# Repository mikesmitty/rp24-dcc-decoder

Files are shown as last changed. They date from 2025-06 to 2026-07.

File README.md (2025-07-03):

# rp24-dcc-decoder
DIY DCC decoder for model railroad locomotives in an E24 form factor suitable for N scale/gauge locomotives

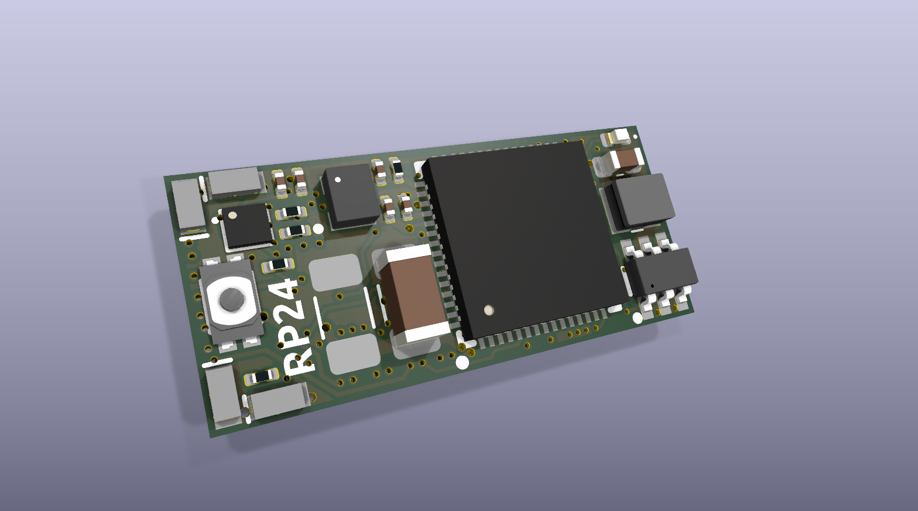
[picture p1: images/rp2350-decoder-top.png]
decoder top

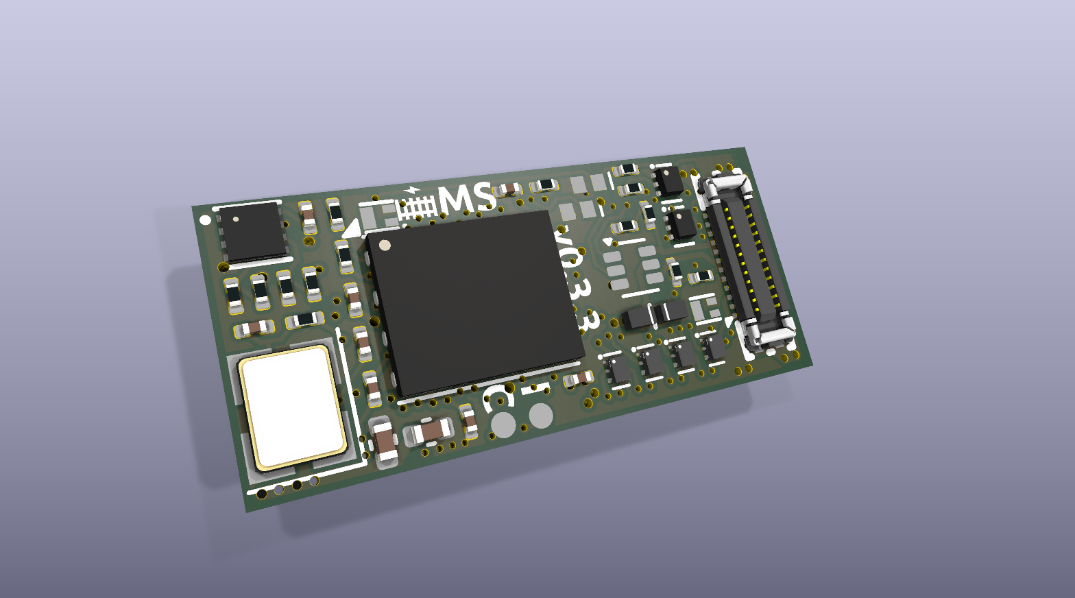
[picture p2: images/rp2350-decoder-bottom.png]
decoder bottom


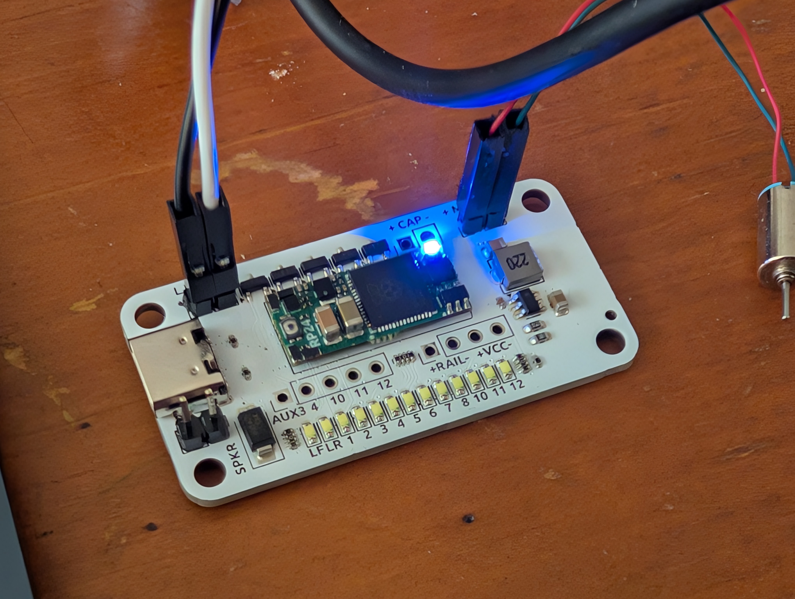
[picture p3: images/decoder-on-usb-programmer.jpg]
decoder on USB programmer

[Decoder identifying to JMRI](https://www.youtube.com/watch?v=m5kexSfDo3k)

## Features
- 8x MOSFET-switched functions
- 5x GPIO pins (3.3V input/output)
- Up to 0.75A motor current
- E24 form factor (approx 20mm x 9mm)
- i2s audio speaker output
- 12V nominal rail voltage (16V max)

# USB Programmer/E24 Tester
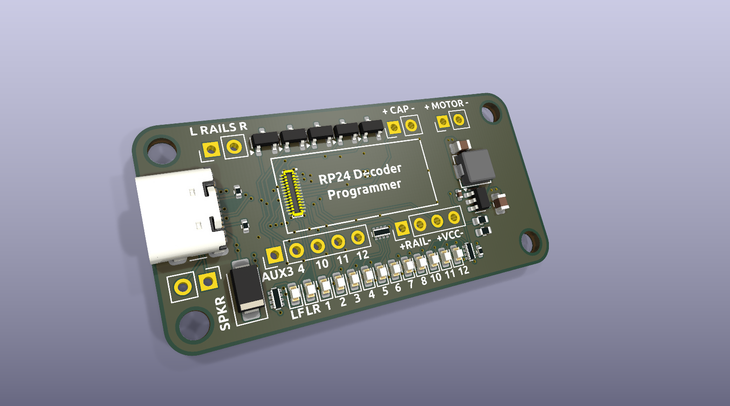
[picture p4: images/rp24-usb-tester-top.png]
programmer top

- USB-C port for easy programming and loading sound files
- Onboard LEDs for all aux outputs for simple decoder testing
- Breakout header for most E24 pins, including speaker, motor, rectified rail power, Vcc, plus all five E24 GPIO pins (Aux 3, 4, 10, 11, 12)
- Programming track input header allows for stationary decoder testing and CV programming

# RP24 Decoder Pinout
| E24 Pin | Function | GPIO Pin |
| --- | --- | --- |
| 1 | Speaker- | USB D- |
| 2 | Speaker+ | USB D+ |
| 3 | GND | GND |
| 4-5 | Motor- | N/A |
| 6-7 | Motor+ | N/A |
| 8 | Cap+ | GPIO20 |
| 9 | Lamp Front | GPIO6 (MOSFET) |
| 10 | Lamp Rear | GPIO7 (MOSFET) |
| 11 | AUX1 | GPIO8 (MOSFET) |
| 12 | AUX2 | GPIO5 (MOSFET) |
| 13 | AUX8 | GPIO4 (MOSFET) |
| 14 | AUX7 | GPIO3 (MOSFET) |
| 15 | AUX6 | GPIO9 (MOSFET) |
| 16 | AUX5 | GPIO2 (MOSFET) |
| 17 | U+ | DC Rail Voltage |
| 18 | Vcc | 3.3V |
| 19 | AUX10 | GPIO10 |
| 20 | AUX4 | GPIO13 |
| 21 | AUX3 | GPIO14 |
| 22 | GND | GND |
| 23 | AUX11 | GPIO0 |
| 24 | AUX12 | GPIO1 |
| N/A | Motor Driver A | GPIO25 |
| N/A | Motor Driver B | GPIO26 |
| N/A | Back EMF A | GPIO28 |
| N/A | Back EMF B | GPIO29 |
| N/A | DCC signal Left Rail | GPIO21 |
| N/A | DCC signal Right Rail | GPIO27 |
| N/A | RailCom Out | GPIO11 |
| N/A | Status LED | GPIO19 |
| N/A | i2s DIN | GPIO22 |
| N/A | i2s BCLK | GPIO23 |
| N/A | i2s LRCLK | GPIO24 |
| N/A | Charge external keepalive capacitor (PWM at very low duty cycle only) | GPIO20 |

# E24 Receiver/Wire Breakout Board
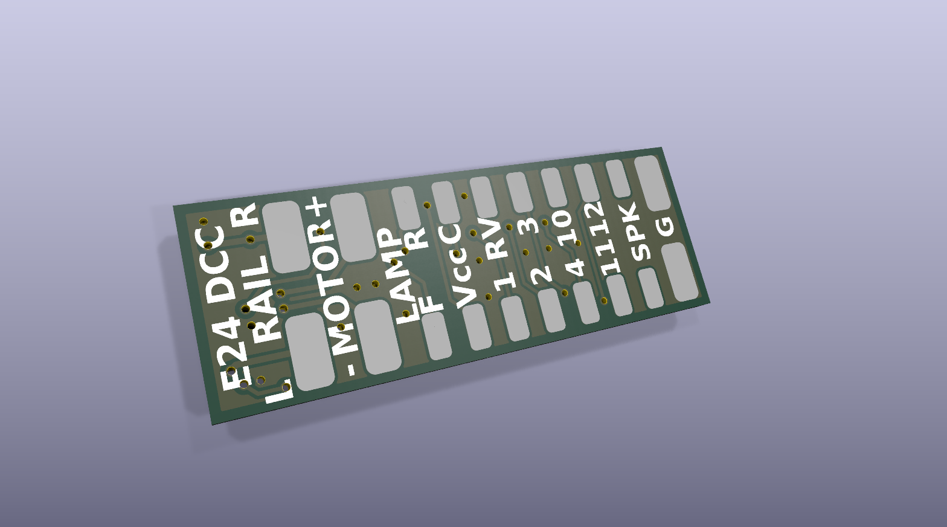
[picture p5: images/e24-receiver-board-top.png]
receiver top

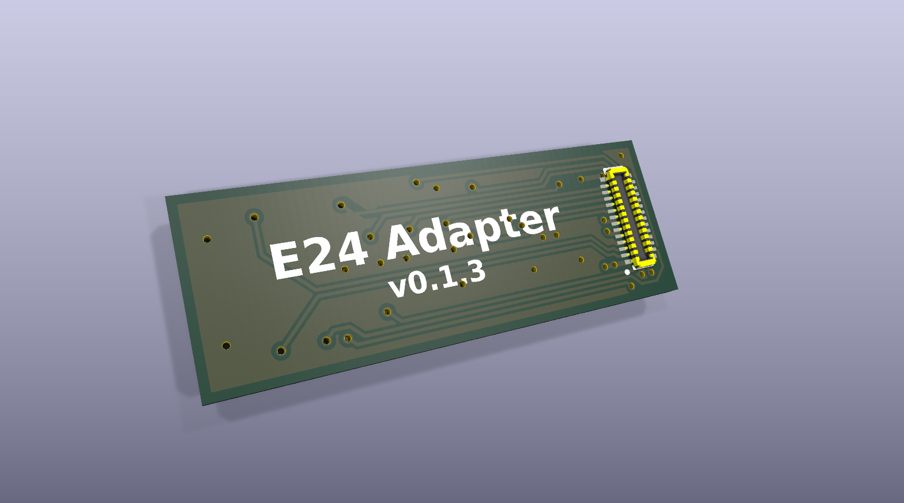
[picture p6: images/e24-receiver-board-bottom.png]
receiver bottom


## Receiver Board Solder Pads
| E24 Pin | Function | Label |
| --- | --- | --- |
| 1 | Speaker- | SPK |
| 2 | Speaker+ | SPK |
| 3 | GND | G |
| 4-5 | Motor- | - MOTOR + |
| 6-7 | Motor+ | - MOTOR + |
| 8 | External Capacitor+ | C |
| 9 | Lamp Front | F LAMP R |
| 10 | Lamp Rear | F LAMP R |
| 11 | AUX1 | 1 |
| 12 | AUX2 | 2 |
| 17 | DC Rail Voltage | RV |
| 18 | Microcontroller Voltage Output | Vcc |
| 19 | AUX10 | 10 |
| 20 | AUX4 | 4 |
| 21 | AUX3 | 3 |
| 22 | GND | G |
| 23 | AUX11 | 11 |
| 24 | AUX12 | 12 |

Inspired by the rp2040-decoder project by gab-k: https://github.com/gab-k/RP2040-Decoder

## Reference:
### E24
- RCD-124 (German): https://normen.railcommunity.de/RCD-124.pdf
- https://dccwiki.com/Locomotive_Interface/E24
### RailCom
- [NMRA S-9.3.2, Section 2](https://www.nmra.org/sites/default/files/s-9.3.2_2012_12_10.pdf)
- Example RailCom transmitter circuit: [CircuitJS](https://www.falstad.com/circuit/circuitjs.html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)

View this project on [CADLAB.io](https://cadlab.io/project/28797).

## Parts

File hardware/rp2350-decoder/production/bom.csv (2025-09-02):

Comment | Designator | Footprint | LCSC
LMBR4020H3T5G | D1,D2,D3,D4 | rp2350-decoder:U-DFN1608-2_L1.6-W0.8-RD | C2852608
MAX98357AEWL+T | U5 | rp2350-decoder:WLP-9_L1.4-W1.3-P0.40-R3-C3-BR | C2682619
100nF | C1,C4,C7,C12,C13,C14,C19 | rp2350-decoder:C_0201_0603Metric | C49062
1K | R2,R4,R5,R15,R17,R19 | rp2350-decoder:R_0201_0603Metric | C270365
6.8K | R1,R6,R7,R8,R12,R13,R16,R18 | rp2350-decoder:R_0201_0603Metric | C423451
AP63203WU | U2 | rp2350-decoder:TSOT-26_L2.9-W1.6-P0.95-LS2.8-BL | C780769
AP1606 | Q1,Q2 | rp2350-decoder:Diodes_DFN1006-3 | C2849580
BZX884C3V3 | D7,D8 | rp2350-decoder:DFN1006-2L-RD | C7529009
NST847BPDP6T5G | Q3,Q4 | rp2350-decoder:SOT-963 | C896443
BOOT | SW1 | rp2350-decoder:SW-SMD_4P-L2.6-W1.6-P0.75-LS3.0 | C913778
22R | R9,R10,R11 | rp2350-decoder:R_0201_0603Metric | C270355
2.2K | R3 | rp2350-decoder:R_0201_0603Metric | C473534
DMN2991UDA-7B | Q5,Q6,Q7,Q8 | rp2350-decoder:X2-DFN0806-6_L0.8-W0.6_X2-DFN0806-6 | C2937136
3.3uH | L2 | rp2350-decoder:L_pol_2016 | C42411119
4.7uF | C9,C10,C15,C17,C18 | rp2350-decoder:C_0201_0603Metric | C335103
RB161QS-40 | D5,D6 | rp2350-decoder:DIO-SMD_L1.0-W0.6-P0.65-RD | C5563750
MD9927 | U6 | rp2350-decoder:WDFN-8_L2.0-W2.0-P0.50-BL-EP | C2684662
47uF | C16 | rp2350-decoder:C_1206_3216Metric | C22367835
10pF | C8,C11 | rp2350-decoder:C_0201_0603Metric | C384956
5052702412 | J3 | rp2350-decoder:CONN-SMD_5052702412 | C724151
W25Q128JVPIQ | U3 | rp2350-decoder:WSON-8-1EP_6x5mm_P1.27mm_EP3.4x4.3mm | C190862
4.7uH | L1 | rp2350-decoder:IND-SMD_L2.5-W2.0-VLS252012CX-150M | C5832360
ABM8-272-T3 | Y1 | rp2350-decoder:Crystal_SMD_3225-4Pin_3.2x2.5mm | C20625731
NCS2220AMUT1G | U1 | rp2350-decoder:DFN-8_L1.6-W1.6-P0.40-BL-EP | C464059
2.2uF | C2,C3 | rp2350-decoder:C_0402_1005Metric | C159814
100uF | C6 | rp2350-decoder:C_1206_3216Metric | C15008
33R | R14 | rp2350-decoder:R_0201_0603Metric | C423356
Blue LED | D9 | rp2350-decoder:LED_0402_1005Metric | C130724
RP2350A | U4 | rp2350-decoder:QFN-60_L7.0-W7.0-P0.40-TL-EP3.4 | C42411118
22uF | C5 | rp2350-decoder:C_0603_1608Metric | C86295

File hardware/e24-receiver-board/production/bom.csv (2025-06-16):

Comment | Designator | Footprint | LCSC
505070-2422 | J1 | e24-receiver-board:CONN-SMD_24P-P0.35_5050702422 | C724143

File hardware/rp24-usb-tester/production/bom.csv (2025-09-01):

Comment | Designator | Footprint | LCSC
22uF | C1,C3 | rp24-usb-tester:C_0805_2012Metric | C45783
SS34 | D13 | rp24-usb-tester:D_SMA | C8678
15K | R4 | rp24-usb-tester:R_0603_1608Metric | C22809
WHITE_LED | D1,D2,D3,D4,D5,D6,D7,D8,D9,D10,D11,D12,D14 | rp24-usb-tester:LED_0603_1608Metric | C2290
505070-2422 | J4 | rp24-usb-tester:CONN-SMD_24P-P0.35_5050702422 | C724143
5.1K | R1,R2 | rp24-usb-tester:R_0402_1005Metric | C25905
USB_C_Receptacle_USB2.0_16P | P1 | rp24-usb-tester:USB_C_Receptacle_GCT_USB4105-xx-A_16P_TopMnt_Horizontal | C2765186
SS8050 | Q1,Q2,Q3,Q4,Q5 | rp24-usb-tester:SOT-23 | C2150
220R | RN1,RN2,RN3 | rp24-usb-tester:R_Array_Concave_4x0402 | C326868
100R | R5 | rp24-usb-tester:R_0402_1005Metric | C25076
22nF | C2 | rp24-usb-tester:C_0402_1005Metric | C1532
MT2492 | U1 | rp24-usb-tester:SOT-23-6 | C89358
22uH | L1 | rp24-usb-tester:IND-SMD_L4.6-W4.2_SMMS0420 | C2894720
110K | R3 | rp24-usb-tester:R_0603_1608Metric | C25805

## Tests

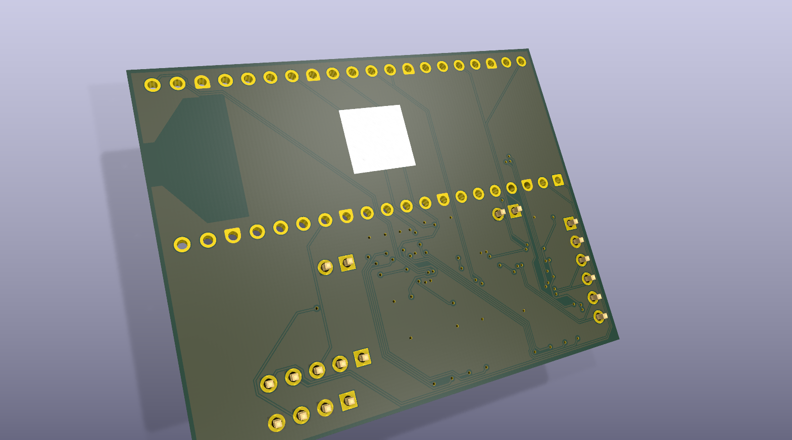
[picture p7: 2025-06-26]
images/pico2-test-mule-bottom.png

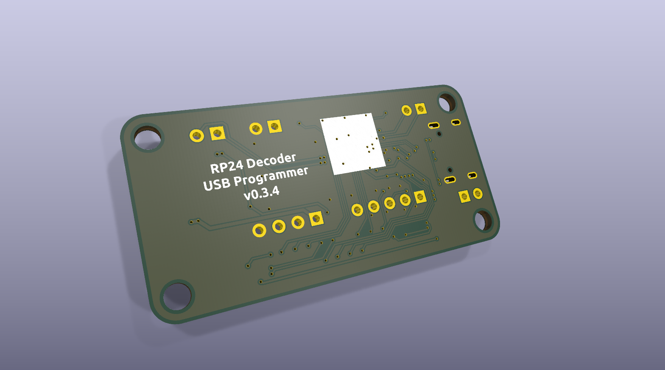
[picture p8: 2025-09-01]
images/rp24-usb-tester-bottom.png

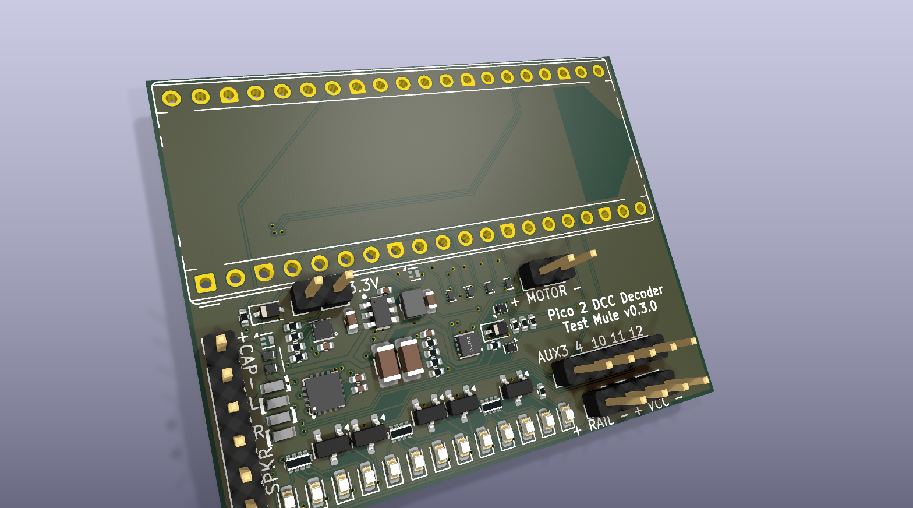
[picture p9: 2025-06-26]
images/pico2-test-mule-top.png

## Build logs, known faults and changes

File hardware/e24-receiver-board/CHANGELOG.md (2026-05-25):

# Changelog

## [0.1.3](https://github.com/mikesmitty/rp24-dcc-decoder/compare/e24-receiver-board-v0.1.2...e24-receiver-board-v0.1.3) (2026-05-25)

### Bug Fixes

* **e24-receiver-board:** switch to 1.0mm thick pcb ([0ce120b](https://github.com/mikesmitty/rp24-dcc-decoder/commit/0ce120b274af8b35ff21393b15e6bb2e795d1627))

## [0.1.2](https://github.com/mikesmitty/rp24-dcc-decoder/compare/e24-receiver-board-v0.1.1...e24-receiver-board-v0.1.2) (2025-06-18)

### Bug Fixes

* un-swap aux11/aux12 pins ([a4e7ca3](https://github.com/mikesmitty/rp24-dcc-decoder/commit/a4e7ca3ea81a5f14c1e2768d6be0322b92dff5f2))

## [0.1.1](https://github.com/mikesmitty/rp24-dcc-decoder/compare/e24-receiver-board-v0.1.0...e24-receiver-board-v0.1.1) (2025-02-23)

### Bug Fixes

* update to kicad 9.0 ([1caf43e](https://github.com/mikesmitty/rp24-dcc-decoder/commit/1caf43eae2056ed70c1e3e898e5bf193f2a6ef8b))

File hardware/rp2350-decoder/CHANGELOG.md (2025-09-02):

# Changelog

## [0.3.3](https://github.com/mikesmitty/rp24-dcc-decoder/compare/rp2350-decoder-v0.3.2...rp2350-decoder-v0.3.3) (2025-09-02)

### Bug Fixes

* clean up silkscreen items ([80477e9](https://github.com/mikesmitty/rp24-dcc-decoder/commit/80477e9bc5986381e135d9b4ac6735943684b929))

## [0.3.2](https://github.com/mikesmitty/rp24-dcc-decoder/compare/rp2350-decoder-v0.3.1...rp2350-decoder-v0.3.2) (2025-09-02)

### Bug Fixes

* switch rail ttl zeners to more common dfn1006 ([5c28789](https://github.com/mikesmitty/rp24-dcc-decoder/commit/5c2878904d47dc9064c75f49efb4027531c81caa))

## [0.3.1](https://github.com/mikesmitty/rp24-dcc-decoder/compare/rp2350-decoder-v0.3.0...rp2350-decoder-v0.3.1) (2025-08-02)

### Bug Fixes

* remove vdc from under connector ([96dd000](https://github.com/mikesmitty/rp24-dcc-decoder/commit/96dd00003e3252300e009753ae7b70a3d9992b5f))

## [0.3.0](https://github.com/mikesmitty/rp24-dcc-decoder/compare/rp2350-decoder-v0.2.0...rp2350-decoder-v0.3.0) (2025-07-03)

### Features

* detect right rail instead of VDC ([ddb6ea3](https://github.com/mikesmitty/rp24-dcc-decoder/commit/ddb6ea383b4f5dc82e747a8a50b871392123b382))

## [0.2.0](https://github.com/mikesmitty/rp24-dcc-decoder/compare/rp2350-decoder-v0.1.2...rp2350-decoder-v0.2.0) (2025-06-26)

### Features

* zener diodes to detect both waves and cutouts ([e85a1f7](https://github.com/mikesmitty/rp24-dcc-decoder/commit/e85a1f764ec8e276c3f0ad8270ab0958ef19c064))

### Bug Fixes

* un-swap capacitor shutdown circuit inputs ([61e69d1](https://github.com/mikesmitty/rp24-dcc-decoder/commit/61e69d1b25d5a35320f998b9ed846dfaee792550))

## [0.1.2](https://github.com/mikesmitty/rp24-dcc-decoder/compare/rp2350-decoder-v0.1.1...rp2350-decoder-v0.1.2) (2025-06-18)

### Bug Fixes

* un-swap usb +/- and aux11/aux12 pins ([1f776d0](https://github.com/mikesmitty/rp24-dcc-decoder/commit/1f776d04f63d8f8768ab01cb2be59e1d0c34c532))

## [0.1.1](https://github.com/mikesmitty/rp24-dcc-decoder/compare/rp2350-decoder-v0.1.0...rp2350-decoder-v0.1.1) (2025-04-01)

### Bug Fixes

* use shorter cap on bottom ([dc6b62a](https://github.com/mikesmitty/rp24-dcc-decoder/commit/dc6b62acc13467da5e2ec5f99067f5d8a516d0b7))

## [0.1.0](https://github.com/mikesmitty/rp24-dcc-decoder/compare/rp2350-decoder-v0.0.4...rp2350-decoder-v0.1.0) (2025-03-14)

### Bug Fixes

* add ground vias near motor driver ([d3c346b](https://github.com/mikesmitty/rp24-dcc-decoder/commit/d3c346b67aaa05e254f0cf5fc2168e786e9e2e42))

### Miscellaneous Chores

* refresh gerbers ([5a95ecd](https://github.com/mikesmitty/rp24-dcc-decoder/commit/5a95ecdd13cb824ea14429b33e8ac43790169a54))

## [0.0.4](https://github.com/mikesmitty/rp24-dcc-decoder/compare/rp2350-decoder-v0.0.3...rp2350-decoder-v0.0.4) (2025-03-08)

### Bug Fixes

* update DCC_TTL debounce capacitor value ([732472c](https://github.com/mikesmitty/rp24-dcc-decoder/commit/732472c98f50376903bb764d93151fdd62facd41))

## [0.0.3](https://github.com/mikesmitty/rp24-dcc-decoder/compare/rp2350-decoder-v0.0.2...rp2350-decoder-v0.0.3) (2025-02-27)

### Bug Fixes

* add debounce capacitor to dcc signal gate ([e6d63b1](https://github.com/mikesmitty/rp24-dcc-decoder/commit/e6d63b166735f56c2b0e96776631d385dbaa79c0))
* update debounce cap value ([7167d29](https://github.com/mikesmitty/rp24-dcc-decoder/commit/7167d2950df77b2c3e97060f00c1a36faaa49821))

## [0.0.2](https://github.com/mikesmitty/rp24-dcc-decoder/compare/rp2350-decoder-v0.0.1...rp2350-decoder-v0.0.2) (2025-02-21)

### Bug Fixes

* lower gate voltage to the dcc signal mosfet ([6cb97c4](https://github.com/mikesmitty/rp24-dcc-decoder/commit/6cb97c431d6f1eea73aafedfe1a02bb732defedf))

## 0.0.1 (2025-02-19)

### Bug Fixes

* switch to recommended crystal ([3851f21](https://github.com/mikesmitty/rp24-dcc-decoder/commit/3851f218dc31737b537c2cfd6a0378fb10ac53e3))

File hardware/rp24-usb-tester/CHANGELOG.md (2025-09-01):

# Changelog

## [0.3.4](https://github.com/mikesmitty/rp24-dcc-decoder/compare/rp24-usb-tester-v0.3.3...rp24-usb-tester-v0.3.4) (2025-09-01)

### Bug Fixes

* 5.1k resistors go to gnd ([8d3d4cb](https://github.com/mikesmitty/rp24-dcc-decoder/commit/8d3d4cb1ccdc5ea720a21019bf442bf9b9f3356d))

## [0.3.3](https://github.com/mikesmitty/rp24-dcc-decoder/compare/rp24-usb-tester-v0.3.2...rp24-usb-tester-v0.3.3) (2025-06-26)

### Bug Fixes

* bump resistors to make LEDs less blinding ([2c4b003](https://github.com/mikesmitty/rp24-dcc-decoder/commit/2c4b00311665386e5128b5ffa2d54e06a1cdbff7))

## [0.3.2](https://github.com/mikesmitty/rp24-dcc-decoder/compare/rp24-usb-tester-v0.3.1...rp24-usb-tester-v0.3.2) (2025-06-18)

### Bug Fixes

* un-swap usb +/- and aux11/aux12 pins ([1f776d0](https://github.com/mikesmitty/rp24-dcc-decoder/commit/1f776d04f63d8f8768ab01cb2be59e1d0c34c532))

## [0.3.1](https://github.com/mikesmitty/rp24-dcc-decoder/compare/rp24-usb-tester-v0.3.0...rp24-usb-tester-v0.3.1) (2025-02-23)

### Bug Fixes

* update fonts and update to kicad 9.0 ([708d73b](https://github.com/mikesmitty/rp24-dcc-decoder/commit/708d73b6243eea81ae5f8e1142ea019fc21d64b7))

## [0.3.0](https://github.com/mikesmitty/rp24-dcc-decoder/compare/rp24-usb-tester-v0.2.0...rp24-usb-tester-v0.3.0) (2025-02-16)

### Features

* add new e24 decoder tester/rp24 programmer ([2115cfc](https://github.com/mikesmitty/rp24-dcc-decoder/commit/2115cfca512d0ccf7c0052a0154a3ae7812805ee))

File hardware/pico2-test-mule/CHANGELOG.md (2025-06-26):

# Changelog

## [0.3.0](https://github.com/mikesmitty/rp24-dcc-decoder/compare/pico2-test-mule-v0.2.5...pico2-test-mule-v0.3.0) (2025-06-26)

### Features

* zener diodes to detect both waves and cutouts ([4520e62](https://github.com/mikesmitty/rp24-dcc-decoder/commit/4520e620aadee4b4d5b46caad65a14fe12c72eaa))

## [0.2.5](https://github.com/mikesmitty/rp24-dcc-decoder/compare/pico2-test-mule-v0.2.4...pico2-test-mule-v0.2.5) (2025-06-26)

### Bug Fixes

* un-swap capacitor shutdown circuit inputs ([61e69d1](https://github.com/mikesmitty/rp24-dcc-decoder/commit/61e69d1b25d5a35320f998b9ed846dfaee792550))

## [0.2.4](https://github.com/mikesmitty/rp24-dcc-decoder/compare/pico2-test-mule-v0.2.3...pico2-test-mule-v0.2.4) (2025-03-08)

### Bug Fixes

* reduce DCC_TTL gate voltage ([8bb2ff3](https://github.com/mikesmitty/rp24-dcc-decoder/commit/8bb2ff398a00977e3ff73f020af28f2f82988a62))
* tweak DCC_TTL debounce cap value ([8bb2ff3](https://github.com/mikesmitty/rp24-dcc-decoder/commit/8bb2ff398a00977e3ff73f020af28f2f82988a62))

## [0.2.3](https://github.com/mikesmitty/rp24-dcc-decoder/compare/pico2-test-mule-v0.2.2...pico2-test-mule-v0.2.3) (2025-02-27)

### Bug Fixes

* combine left side headers ([8ec852f](https://github.com/mikesmitty/rp24-dcc-decoder/commit/8ec852fca5bbab5de6a5f5c44ad002712fa8c7b9))
* minor trace rerouting ([e47bcee](https://github.com/mikesmitty/rp24-dcc-decoder/commit/e47bceee5babf562b35d44f7a8becf1b144da8fe))

## [0.2.2](https://github.com/mikesmitty/rp24-dcc-decoder/compare/pico2-test-mule-v0.2.1...pico2-test-mule-v0.2.2) (2025-02-26)

### Bug Fixes

* add debounce capacitor to dcc signal gate ([8eee1f6](https://github.com/mikesmitty/rp24-dcc-decoder/commit/8eee1f6eb663765a5d2aa30e55fa527f804a481f))

## [0.2.1](https://github.com/mikesmitty/rp24-dcc-decoder/compare/pico2-test-mule-v0.2.0...pico2-test-mule-v0.2.1) (2025-02-23)

### Bug Fixes

* update to kicad 9.0 ([98311b6](https://github.com/mikesmitty/rp24-dcc-decoder/commit/98311b61241b5b43cae7abeaa5af38be45a82724))

## [0.2.0](https://github.com/mikesmitty/rp24-dcc-decoder/compare/pico2-test-mule-v0.1.0...pico2-test-mule-v0.2.0) (2025-02-16)

### Features

* add new pico2 test mule for firmware dev ([0d0d831](https://github.com/mikesmitty/rp24-dcc-decoder/commit/0d0d831cf1059fa60065890cc0ef8ffa47a683c0))

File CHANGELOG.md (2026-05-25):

# Changelog

## [0.6.0](https://github.com/mikesmitty/rp24-dcc-decoder/compare/v0.5.1...v0.6.0) (2026-05-25)

### Features

* Update module github.com/tinygo-org/pio to v0.3.0 ([#76](https://github.com/mikesmitty/rp24-dcc-decoder/issues/76)) ([c56449e](https://github.com/mikesmitty/rp24-dcc-decoder/commit/c56449e195b2d09360eefeda9650cc8935bdbf73))

### Bug Fixes

* **deps:** update golang.org/x/exp digest to 74f9aab ([#72](https://github.com/mikesmitty/rp24-dcc-decoder/issues/72)) ([b6f4512](https://github.com/mikesmitty/rp24-dcc-decoder/commit/b6f4512f8ab333e81455b3949f5a69fc011e2c3c))
* **deps:** update golang.org/x/exp digest to e25ba8c ([#68](https://github.com/mikesmitty/rp24-dcc-decoder/issues/68)) ([ddd0e29](https://github.com/mikesmitty/rp24-dcc-decoder/commit/ddd0e299a88e69853f8f733d55ec5d8c079d945e))
* Update module github.com/mikesmitty/tinypid to v1.1.2 ([#66](https://github.com/mikesmitty/rp24-dcc-decoder/issues/66)) ([368d651](https://github.com/mikesmitty/rp24-dcc-decoder/commit/368d651679ab84afcd6bbbe5192ec00418eea2de))

## [0.5.1](https://github.com/mikesmitty/rp24-dcc-decoder/compare/v0.5.0...v0.5.1) (2025-10-31)

### Bug Fixes

* **deps:** update golang.org/x/exp digest to 42675ad ([#55](https://github.com/mikesmitty/rp24-dcc-decoder/issues/55)) ([8c79fb0](https://github.com/mikesmitty/rp24-dcc-decoder/commit/8c79fb0a1e2817a186f70df58597ea7953df09a9))
* **deps:** update golang.org/x/exp digest to 51f8813 ([#51](https://github.com/mikesmitty/rp24-dcc-decoder/issues/51)) ([7244902](https://github.com/mikesmitty/rp24-dcc-decoder/commit/724490245d16994d8783d3452a990d92a2ad6594))
* **deps:** update golang.org/x/exp digest to 8b4c13b ([#56](https://github.com/mikesmitty/rp24-dcc-decoder/issues/56)) ([41abde0](https://github.com/mikesmitty/rp24-dcc-decoder/commit/41abde0aa6662b7aac0c94eba1e1472ebc4626d6))
* **deps:** update golang.org/x/exp digest to a4bb9ff ([#64](https://github.com/mikesmitty/rp24-dcc-decoder/issues/64)) ([0dec770](https://github.com/mikesmitty/rp24-dcc-decoder/commit/0dec7704e9ae3c3ff21456ee4219fc70a096a228))
* **deps:** update golang.org/x/exp digest to d2f985d ([#63](https://github.com/mikesmitty/rp24-dcc-decoder/issues/63)) ([2d0001a](https://github.com/mikesmitty/rp24-dcc-decoder/commit/2d0001a6984248e023278804a349cace2932afc7))
* **deps:** update golang.org/x/exp digest to df92998 ([#61](https://github.com/mikesmitty/rp24-dcc-decoder/issues/61)) ([d0d50a4](https://github.com/mikesmitty/rp24-dcc-decoder/commit/d0d50a4dca40c667b3305ba84ea4512c51026bc5))

## [0.5.0](https://github.com/mikesmitty/rp24-dcc-decoder/compare/v0.4.0...v0.5.0) (2025-08-02)

### Features

* add early stage backemf motor control ([a25211d](https://github.com/mikesmitty/rp24-dcc-decoder/commit/a25211db5da32ed0f17aac7e8010aa097b95d403))
* add watchdog for signal cutout ([a25211d](https://github.com/mikesmitty/rp24-dcc-decoder/commit/a25211db5da32ed0f17aac7e8010aa097b95d403))

### Bug Fixes

* add watchdog timer ([11b6576](https://github.com/mikesmitty/rp24-dcc-decoder/commit/11b657602e25fd6cb13ee2e36697979c7ffdf19e))
* defend against panics from invalid messages ([ffdcd00](https://github.com/mikesmitty/rp24-dcc-decoder/commit/ffdcd002d98769922d42dc0cb6c4ae6520a1eed1))
* **deps:** update golang.org/x/exp digest to 645b1fa ([#48](https://github.com/mikesmitty/rp24-dcc-decoder/issues/48)) ([313a73c](https://github.com/mikesmitty/rp24-dcc-decoder/commit/313a73c76a07aca35d5ec08aace8f12d40190b84))

## [0.4.0](https://github.com/mikesmitty/rp24-dcc-decoder/compare/v0.3.0...v0.4.0) (2025-07-03)

### Features

* detect right rail instead of VDC ([ddb6ea3](https://github.com/mikesmitty/rp24-dcc-decoder/commit/ddb6ea383b4f5dc82e747a8a50b871392123b382))

### Bug Fixes

* fix cv write bugs ([bde219d](https://github.com/mikesmitty/rp24-dcc-decoder/commit/bde219d6429ba6914b5c6cf0a966d8f1f6285c03))

## [0.3.0](https://github.com/mikesmitty/rp24-dcc-decoder/compare/v0.2.0...v0.3.0) (2025-07-02)

### Features

* add basic ack functionality ([f5d5ae6](https://github.com/mikesmitty/rp24-dcc-decoder/commit/f5d5ae6a7456e60b06a05bcb1aa5879a4456d067))
* overhaul motor controller ([99d4ee8](https://github.com/mikesmitty/rp24-dcc-decoder/commit/99d4ee804c4e48eec4de7833bd355d6945b4c168))

### Bug Fixes

* add missing import ([c64d183](https://github.com/mikesmitty/rp24-dcc-decoder/commit/c64d183ea62e0248e458cf550c6ac9474b331468))
* enable motor control lockout mutex ([a0d5d45](https://github.com/mikesmitty/rp24-dcc-decoder/commit/a0d5d454318a02a385601f88090ae5ff6baa3785))

## [0.2.0](https://github.com/mikesmitty/rp24-dcc-decoder/compare/v0.1.0...v0.2.0) (2025-03-23)

### Features

* add motor control ([26f15c5](https://github.com/mikesmitty/rp24-dcc-decoder/commit/26f15c5dfaf2c012a957807f6a8c6f23504239b2))
* update go to 1.24.1 ([fa4d50e](https://github.com/mikesmitty/rp24-dcc-decoder/commit/fa4d50ecfa9deb2a11a8e6c42269f53fc977b5fc))

### Bug Fixes

* correct function offset indexes ([ea1fa88](https://github.com/mikesmitty/rp24-dcc-decoder/commit/ea1fa88235f76972585350e53caf278e261eab66))
* disable directional outputs when switching direction ([26f15c5](https://github.com/mikesmitty/rp24-dcc-decoder/commit/26f15c5dfaf2c012a957807f6a8c6f23504239b2))
* embed tagged version at build time ([009c713](https://github.com/mikesmitty/rp24-dcc-decoder/commit/009c713c4f9f1269592b5a993daec2d3cb00894c))

## [0.1.0](https://github.com/mikesmitty/rp24-dcc-decoder/compare/v0.0.1...v0.1.0) (2025-03-23)

### Features

* add function/output mapping and general cleanup ([d0cb788](https://github.com/mikesmitty/rp24-dcc-decoder/commit/d0cb788c2bafbf0a5f7e7699384653fa242ed265))
* add initial rough draft packages ([94049e1](https://github.com/mikesmitty/rp24-dcc-decoder/commit/94049e1630e36b6ee2894b043c71bf0edd1b20ed))

### Bug Fixes

* clean up motor CV definitions ([ddde344](https://github.com/mikesmitty/rp24-dcc-decoder/commit/ddde344ea2ec8ca0b557756d1d70a4cd0f5d16f2))
* cleanup and recategorize future changes ([19ba12f](https://github.com/mikesmitty/rp24-dcc-decoder/commit/19ba12f27c25d43e626b6c9f27d5b2940e60cd3c))
* **deps:** update module github.com/tinygo-org/pio to v0.2.0 ([#29](https://github.com/mikesmitty/rp24-dcc-decoder/issues/29)) ([1cd45db](https://github.com/mikesmitty/rp24-dcc-decoder/commit/1cd45db01dc1dcfaa50f6969206e61af102fbd75))
* handle double uno-reverse direction of travel swaps ([be3c416](https://github.com/mikesmitty/rp24-dcc-decoder/commit/be3c4161fb6095494123a71e18ab77e418a75bd7))
* implement CV21/CV22 consist function masks ([5bd3659](https://github.com/mikesmitty/rp24-dcc-decoder/commit/5bd3659a5e1a80b0e5bbf3bf347243e021f56986))
* load new index when CV31/CV32 are set ([5bd3659](https://github.com/mikesmitty/rp24-dcc-decoder/commit/5bd3659a5e1a80b0e5bbf3bf347243e021f56986))
* make dcc functions map to outputs ([8c448f2](https://github.com/mikesmitty/rp24-dcc-decoder/commit/8c448f22cd591466faf243c840eda684ffdd44ae))
* misc cleanup and add CVs ([d987945](https://github.com/mikesmitty/rp24-dcc-decoder/commit/d98794585a2216fc0b2ad298861d51faa18c7f80))
* squash various bugs ([8c448f2](https://github.com/mikesmitty/rp24-dcc-decoder/commit/8c448f22cd591466faf243c840eda684ffdd44ae))
* undo copy/paste bugs ([cc430f6](https://github.com/mikesmitty/rp24-dcc-decoder/commit/cc430f6f70852d3c441f914362f6252d59be9529))

## 0.0.1 (2025-02-16)

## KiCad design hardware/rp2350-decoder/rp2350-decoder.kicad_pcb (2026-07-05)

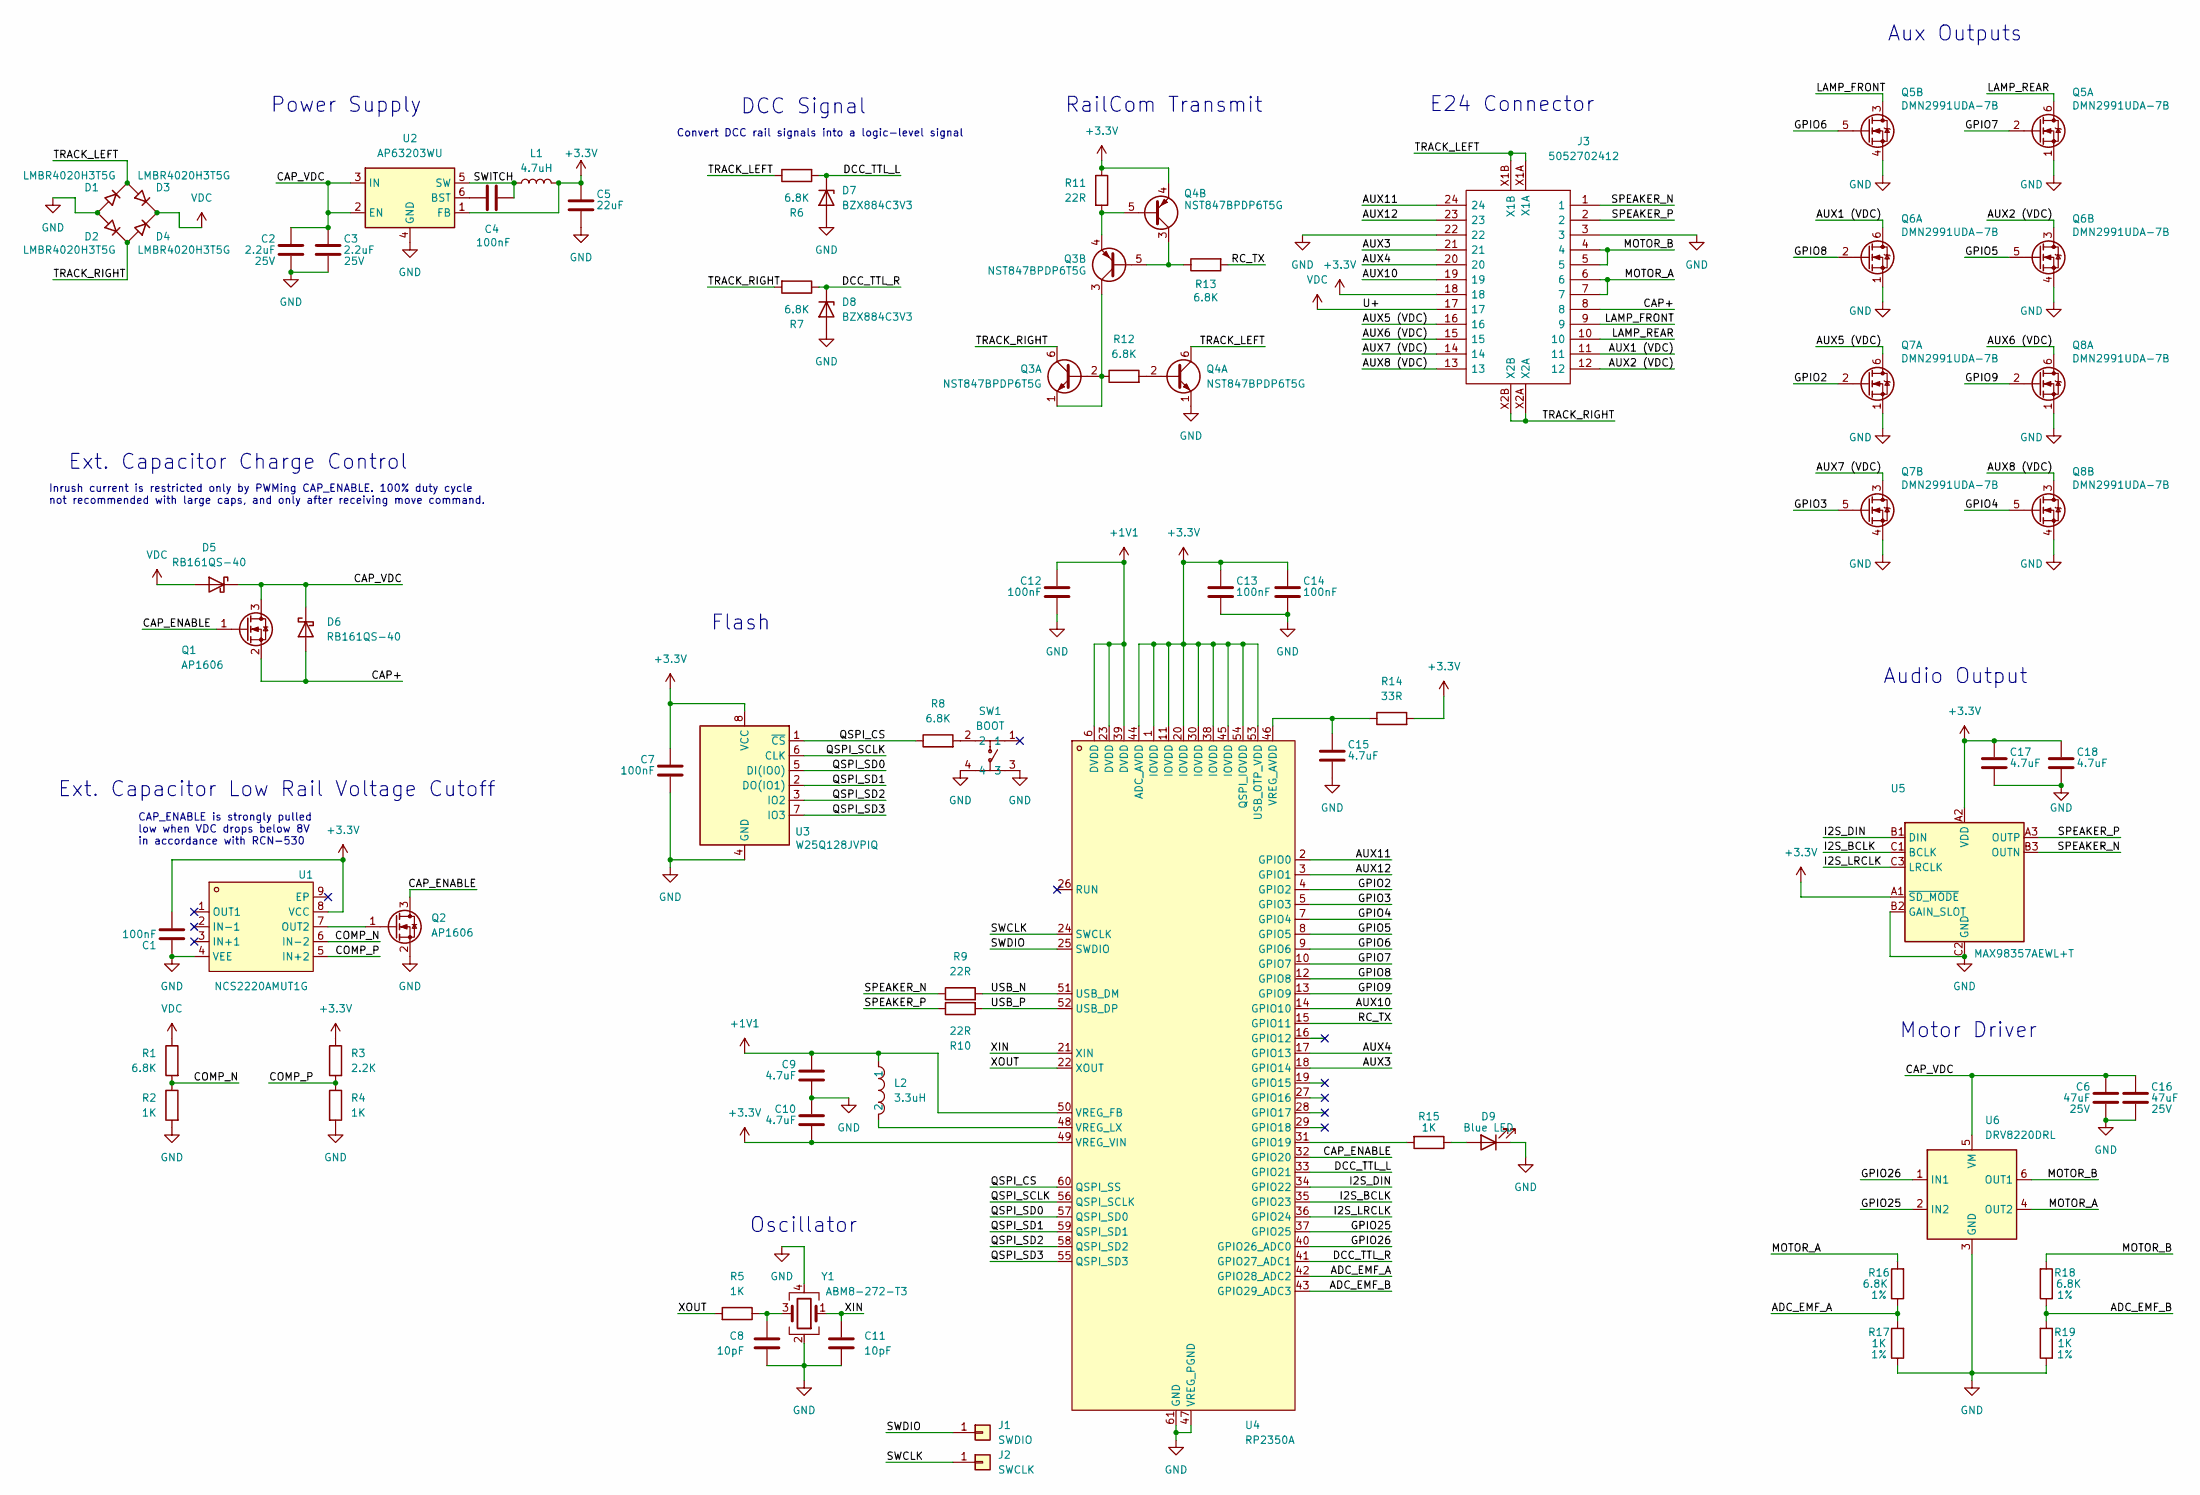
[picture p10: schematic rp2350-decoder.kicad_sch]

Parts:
C1, C4, C7, C12, C13, C14: 100nF; C_0201_0603Metric; LCSC C49062
C2, C3: 2.2uF; C_0402_1005Metric; Voltage 25V; LCSC C159814
C5: 22uF; C_0603_1608Metric; LCSC C86295
C6, C16: 47uF; C_1206_3216Metric; Voltage 25V; LCSC C22367835
C8, C11: 10pF; C_0201_0603Metric; LCSC C384956
C9, C10, C15, C17, C18: 4.7uF; C_0201_0603Metric; LCSC C335103
D1, D2, D3, D4: LMBR4020H3T5G; U-DFN1608-2_L1.6-W0.8-RD; LCSC C2852608
D5, D6: RB161QS-40; DIO-SMD_L1.0-W0.6-P0.65-RD; LCSC C5563750
D7, D8: BZX884C3V3; DFN1006-2L-RD; LCSC C7529009
D9: Blue LED; LED_0402_1005Metric; LCSC C130724
J1: SWDIO; Pogo Pad 0.8mm
J2: SWCLK; Pogo Pad 0.8mm
J3: 5052702412; CONN-SMD_5052702412; LCSC C724151
L1: 4.7uH; IND-SMD_L2.5-W2.0-VLS252012CX-150M; LCSC C5832360
L2: 3.3uH; L_pol_2016; LCSC C42411119
Q1, Q2: AP1606; Diodes_DFN1006-3; LCSC C2849580
Q3, Q4: NST847BPDP6T5G; SOT-963; LCSC C896443
Q5, Q6, Q7, Q8: DMN2991UDA-7B; X2-DFN0806-6_L0.8-W0.6_X2-DFN0806-6; LCSC C2937136
R1, R6, R7, R8, R12, R13: 6.8K; R_0201_0603Metric; LCSC C423451
R2, R4, R5, R15: 1K; R_0201_0603Metric; LCSC C270365
R3: 2.2K; R_0201_0603Metric; LCSC C473534
R9, R10, R11: 22R; R_0201_0603Metric; LCSC C270355
R14: 33R; R_0201_0603Metric; LCSC C423356
R16, R18: 6.8K; R_0201_0603Metric; Tolerance 1%; LCSC C423451
R17, R19: 1K; R_0201_0603Metric; Tolerance 1%; LCSC C270365
SW1: BOOT; SW-SMD_4P-L2.6-W1.6-P0.75-LS3.0; LCSC C913778
U1: NCS2220AMUT1G; DFN-8_L1.6-W1.6-P0.40-BL-EP; LCSC C464059
U2: AP63203WU; TSOT-26_L2.9-W1.6-P0.95-LS2.8-BL; LCSC C780769
U3: W25Q128JVPIQ; WSON-8-1EP_6x5mm_P1.27mm_EP3.4x4.3mm; LCSC C190862
U4: RP2350A; QFN-60_L7.0-W7.0-P0.40-TL-EP3.4; LCSC C42411118
U5: MAX98357AEWL+T; WLP-9_L1.4-W1.3-P0.40-R3-C3-BR; LCSC C2682619
U6: DRV8220DRL; SOT-563; LCSC C3681351
Y1: ABM8-272-T3; Crystal_SMD_3225-4Pin_3.2x2.5mm; LCSC C20625731

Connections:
+1V1: C9.1, C12.1, L2.1, U4.6 (DVDD), U4.23 (DVDD), U4.39 (DVDD), U4.50 (VREG_FB)
+3.3V: C1.2, C5.1, C7.1, C10.2, C13.1, C14.1, C17.1, C18.1, J3.18, L1.2, Q4.4 (E2), R3.1, R11.1, R14.2, U1.8 (VCC), U2.1 (FB), U3.8 (VCC), U4.1 (IOVDD), U4.11 (IOVDD), U4.20 (IOVDD), U4.30 (IOVDD), U4.38 (IOVDD), U4.44 (ADC_AVDD), U4.45 (IOVDD), U4.49 (VREG_VIN), U4.53 (USB_OTP_VDD), U4.54 (QSPI_IOVDD), U5.A1 (~SD_MODE), U5.A2 (VDD)
/ADC_EMF_A: R16.1, R17.2, U4.42 (GPIO28_ADC2)
/ADC_EMF_B: R18.1, R19.2, U4.43 (GPIO29_ADC3)
/AUX1 (VDC): J3.11, Q6.6 (D1)
/AUX2 (VDC): J3.12, Q6.3 (D2)
/AUX3: J3.21, U4.18 (GPIO14)
/AUX4: J3.20, U4.17 (GPIO13)
/AUX5 (VDC): J3.16, Q7.6 (D1)
/AUX6 (VDC): J3.15, Q8.6 (D1)
/AUX7 (VDC): J3.14, Q7.3 (D2)
/AUX8 (VDC): J3.13, Q8.3 (D2)
/AUX10: J3.19, U4.14 (GPIO10)
/AUX11: J3.24, U4.2 (GPIO0)
/AUX12: J3.23, U4.3 (GPIO1)
/CAP+: D6.2 (A), J3.8, Q1.2 (S)
/CAP_ENABLE: Q1.1 (G), Q2.3 (D), U4.32 (GPIO20)
/CAP_VDC: C2.1, C3.1, C6.1, C16.1, D5.1 (K), D6.1 (K), Q1.3 (D), U2.2 (EN), U2.3 (IN), U6.5 (VM)
/COMP_N: R1.2, R2.1, U1.6 (IN−2)
/COMP_P: R3.2, R4.1, U1.5 (IN+2)
/DCC_TTL_L: D7.1 (K), R6.2, U4.33 (GPIO21)
/DCC_TTL_R: D8.1 (K), R7.1, U4.41 (GPIO27_ADC1)
/GPIO2: Q7.2 (G1), U4.4 (GPIO2)
/GPIO3: Q7.5 (G2), U4.5 (GPIO3)
/GPIO4: Q8.5 (G2), U4.7 (GPIO4)
/GPIO5: Q6.5 (G2), U4.8 (GPIO5)
/GPIO6: Q5.5 (G2), U4.9 (GPIO6)
/GPIO7: Q5.2 (G1), U4.10 (GPIO7)
/GPIO8: Q6.2 (G1), U4.12 (GPIO8)
/GPIO9: Q8.2 (G1), U4.13 (GPIO9)
/GPIO25: U4.37 (GPIO25), U6.2 (IN2)
/GPIO26: U4.40 (GPIO26_ADC0), U6.1 (IN1)
/I2S_BCLK: U4.35 (GPIO23), U5.C1 (BCLK)
/I2S_DIN: U4.34 (GPIO22), U5.B1 (DIN)
/I2S_LRCLK: U4.36 (GPIO24), U5.C3 (LRCLK)
/LAMP_FRONT: J3.9, Q5.3 (D2)
/LAMP_REAR: J3.10, Q5.6 (D1)
/MOTOR_A: J3.6, J3.7, R16.2, U6.4 (OUT2)
/MOTOR_B: J3.4, J3.5, R18.2, U6.6 (OUT1)
/QSPI_CS: R8.1, U3.1 (~CS), U4.60 (QSPI_SS)
/QSPI_SCLK: U3.6 (CLK), U4.56 (QSPI_SCLK)
/QSPI_SD0: U3.5 (DI(IO0)), U4.57 (QSPI_SD0)
/QSPI_SD1: U3.2 (DO(IO1)), U4.59 (QSPI_SD1)
/QSPI_SD2: U3.3 (IO2), U4.58 (QSPI_SD2)
/QSPI_SD3: U3.7 (IO3), U4.55 (QSPI_SD3)
/RC_TX: R13.2, U4.15 (GPIO11)
/SPEAKER_N: J3.1, R9.1, U5.B3 (OUTN)
/SPEAKER_P: J3.2, R10.1, U5.A3 (OUTP)
/SWCLK: J2.1, U4.24 (SWCLK)
/SWDIO: J1.1, U4.25 (SWDIO)
/SWITCH: C4.2, L1.1, U2.5 (SW)
/TRACK_LEFT: D1.1 (K), D3.2 (A), J3.X1A, J3.X1B, Q4.6 (C1), R6.1
/TRACK_RIGHT: D2.1 (K), D4.2 (A), J3.X2A, J3.X2B, Q3.6 (C1), R7.2
/USB_N: R9.2, U4.51 (USB_DM)
/USB_P: R10.2, U4.52 (USB_DP)
/XIN: C11.1, U4.21 (XIN), Y1.1
/XOUT: R5.2, U4.22 (XOUT)
GND: C1.1, C2.2, C3.2, C5.2, C6.2, C7.2, C8.2, C9.2, C10.1, C11.2, C12.2, C13.2, C14.2, C15.2, C16.2, C17.2, C18.2, D1.2 (A), D2.2 (A), D7.2 (A), D8.2 (A), D9.1 (K), J3.3, J3.22, Q2.2 (S), Q4.1 (E1), Q5.1 (S1), Q5.4 (S2), Q6.1 (S1), Q6.4 (S2), Q7.1 (S1), Q7.4 (S2), Q8.1 (S1), Q8.4 (S2), R2.2, R4.2, R17.1, R19.1, SW1.3, SW1.4, U1.4 (VEE), U2.4 (GND), U3.4 (GND), U3.9 (GND), U4.47 (VREG_PGND), U4.61 (GND), U5.B2 (GAIN_SLOT), U5.C2 (GND), U6.3 (GND), Y1.2, Y1.4
unnamed: C8.1, R5.1, Y1.3
unnamed: D9.2 (A), R15.1
unnamed: Q2.1 (G), U1.7 (OUT2)
unnamed: Q3.1 (E1), Q3.2 (B1), Q3.3 (C2), R12.1
unnamed: Q3.5 (B2), Q4.3 (C2), R13.1
unnamed: Q3.4 (E2), Q4.5 (B2), R11.2
unnamed: Q4.2 (B1), R12.2
unnamed: R8.2, SW1.2
unnamed: C4.1, U2.6 (BST)
unnamed: R15.2, U4.31 (GPIO19)
unnamed: C15.1, R14.1, U4.46 (VREG_AVDD)
unnamed: L2.2, U4.48 (VREG_LX)
VDC: D3.1 (K), D4.1 (K), D5.2 (A), J3.17, R1.1

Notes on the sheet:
Inrush current is restricted only by PWMing CAP_ENABLE. 100% duty cycle not recommended with large caps, and only after receiving move command.
CAP_ENABLE is strongly pulled low when VDC drops below 8V in accordance with RCN-530
Aux Outputs
RailCom Transmit
Convert DCC rail signals into a logic-level signal
Motor Driver
Oscillator
Power Supply
Flash
Ext. Capacitor Low Rail Voltage Cutoff
Ext. Capacitor Charge Control
Audio Output
E24 Connector
DCC Signal

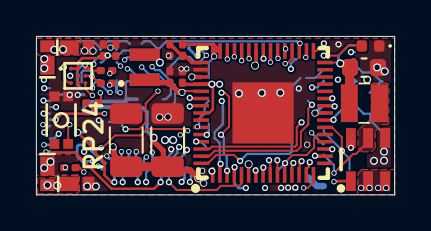
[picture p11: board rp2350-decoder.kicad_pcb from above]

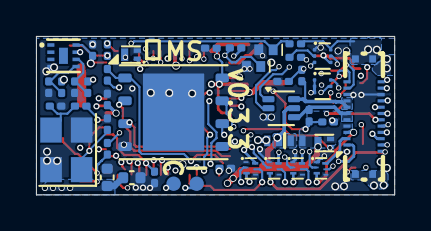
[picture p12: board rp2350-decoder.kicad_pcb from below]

Board: 6 copper layers, 19.9 x 8.8 mm, 67 parts (43 on the bottom side), 71 nets.

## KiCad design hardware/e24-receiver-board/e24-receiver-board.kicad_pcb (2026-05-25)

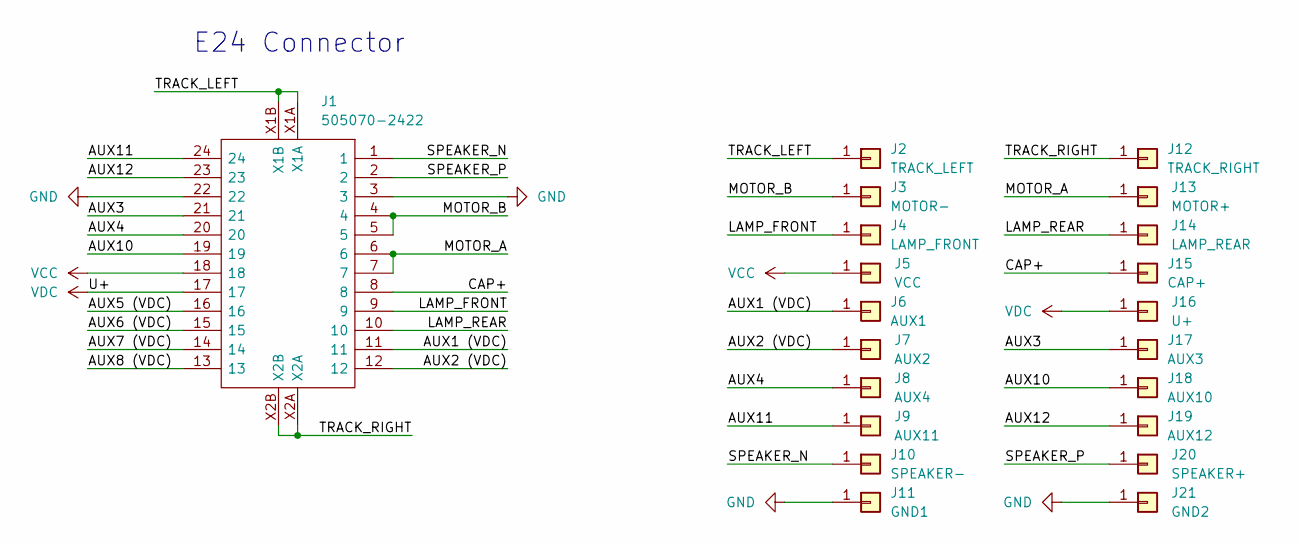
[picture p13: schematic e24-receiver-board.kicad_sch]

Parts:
J1: 505070-2422; CONN-SMD_24P-P0.35_5050702422; Manufacturer_Part_Number 505070-2422; LCSC C724143
J2: TRACK_LEFT; SolderWirePad_1x01_SMD_1.5x3mm
J3: MOTOR-; SolderWirePad_1x01_SMD_1.5x3mm
J4: LAMP_FRONT; SolderWirePad_1x01_SMD_1x2mm
J5: VCC; SolderWirePad_1x01_SMD_1x2mm
J6: AUX1; SolderWirePad_1x01_SMD_1x2mm
J7: AUX2; SolderWirePad_1x01_SMD_1x2mm
J8: AUX4; SolderWirePad_1x01_SMD_1x2mm
J9: AUX11; SolderWirePad_1x01_SMD_1x2mm
J10: SPEAKER-; SolderWirePad_1x01_SMD_1x2mm
J11: GND1; SolderWirePad_1x01_SMD_1.5x3mm
J12: TRACK_RIGHT; SolderWirePad_1x01_SMD_1.5x3mm
J13: MOTOR+; SolderWirePad_1x01_SMD_1.5x3mm
J14: LAMP_REAR; SolderWirePad_1x01_SMD_1x2mm
J15: CAP+; SolderWirePad_1x01_SMD_1x2mm
J16: U+; SolderWirePad_1x01_SMD_1x2mm
J17: AUX3; SolderWirePad_1x01_SMD_1x2mm
J18: AUX10; SolderWirePad_1x01_SMD_1x2mm
J19: AUX12; SolderWirePad_1x01_SMD_1x2mm
J20: SPEAKER+; SolderWirePad_1x01_SMD_1x2mm
J21: GND2; SolderWirePad_1x01_SMD_1.5x3mm

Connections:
/AUX1 (VDC): J1.11, J6.1
/AUX2 (VDC): J1.12, J7.1
/AUX3: J1.21, J17.1
/AUX4: J1.20, J8.1
/AUX5 (VDC): J1.16
/AUX6 (VDC): J1.15
/AUX7 (VDC): J1.14
/AUX8 (VDC): J1.13
/AUX10: J1.19, J18.1
/AUX11: J1.24, J9.1
/AUX12: J1.23, J19.1
/CAP+: J1.8, J15.1
/LAMP_FRONT: J1.9, J4.1
/LAMP_REAR: J1.10, J14.1
/MOTOR_A: J1.6, J1.7, J13.1
/MOTOR_B: J1.4, J1.5, J3.1
/SPEAKER_N: J1.1, J10.1
/SPEAKER_P: J1.2, J20.1
/TRACK_LEFT: J1.X1A, J1.X1B, J2.1
/TRACK_RIGHT: J1.X2A, J1.X2B, J12.1
GND: J1.3, J1.22, J11.1, J21.1
VCC: J1.18, J5.1
VDC: J1.17, J16.1

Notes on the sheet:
E24 Connector

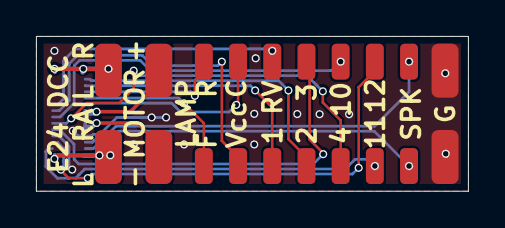
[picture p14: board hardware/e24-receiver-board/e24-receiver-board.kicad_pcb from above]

Board: 2 copper layers, 24.0 x 8.6 mm, 21 parts (1 on the bottom side), 19 nets.

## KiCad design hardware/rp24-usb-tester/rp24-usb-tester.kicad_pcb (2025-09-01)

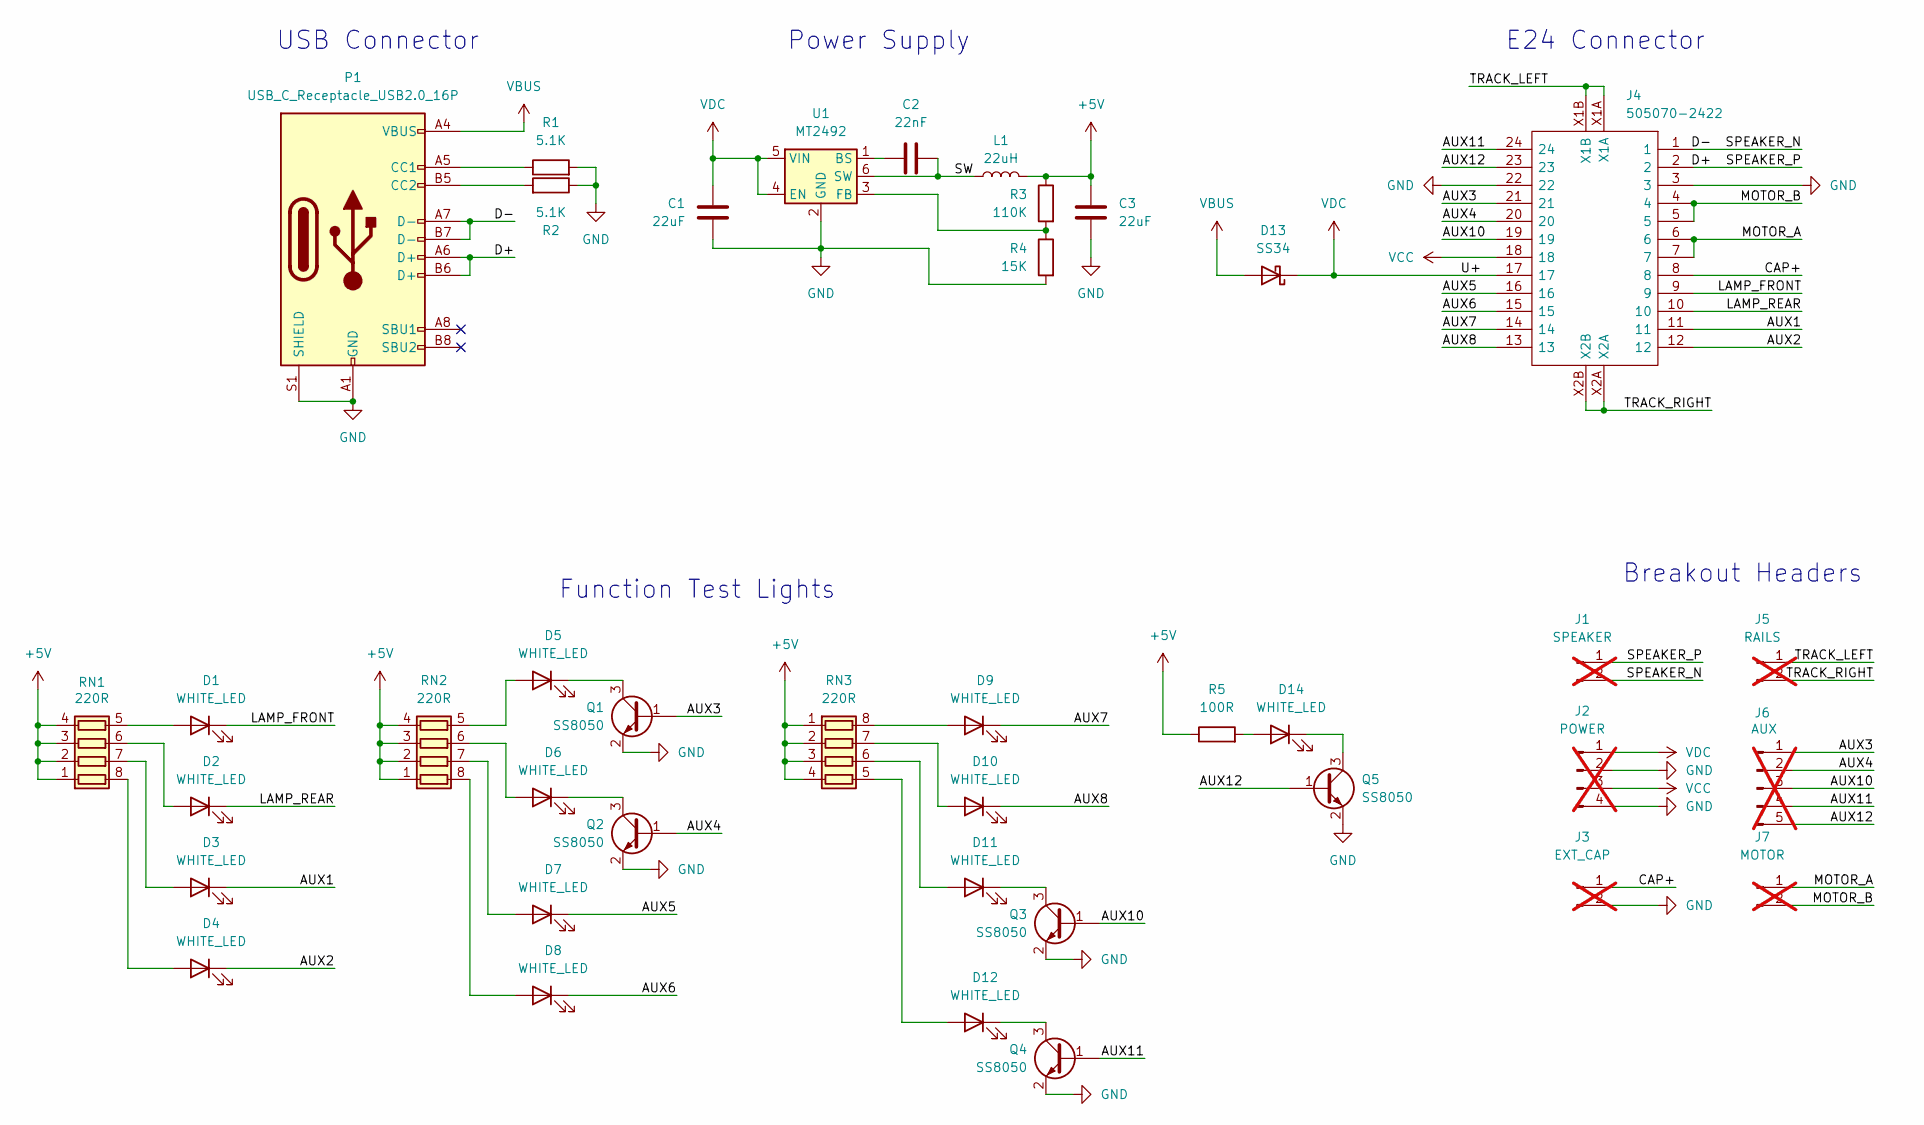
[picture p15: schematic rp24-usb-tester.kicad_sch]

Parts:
C1, C3: 22uF; C_0805_2012Metric; LCSC C45783
C2: 22nF; C_0402_1005Metric; LCSC C1532
D1, D2, D3, D4, D5, D6, D7, D8, D9, D10, D11, D12, D14: WHITE_LED; LED_0603_1608Metric; LCSC C2290
D13: SS34; D_SMA; LCSC C8678
J1: SPEAKER; PinHeader_1x02_P2.54mm_Vertical; not fitted
J2: POWER; PinHeader_1x04_P2.54mm_Vertical; not fitted
J3: EXT_CAP; PinHeader_1x02_P2.54mm_Vertical; not fitted
J4: 505070-2422; CONN-SMD_24P-P0.35_5050702422; Manufacturer_Part_Number 505070-2422; LCSC C724143
J5: RAILS; PinHeader_1x02_P2.54mm_Vertical; not fitted
J6: AUX; PinHeader_1x05_P2.54mm_Vertical; not fitted
J7: MOTOR; PinHeader_1x02_P2.54mm_Vertical; not fitted
L1: 22uH; IND-SMD_L4.6-W4.2_SMMS0420; LCSC C2894720
P1: USB_C_Receptacle_USB2.0_16P; USB_C_Receptacle_GCT_USB4105-xx-A_16P_TopMnt_Horizontal; LCSC C2765186
Q1, Q2, Q3, Q4, Q5: SS8050; SOT-23; LCSC C2150
R1, R2: 5.1K; R_0402_1005Metric; LCSC C25905
R3: 110K; R_0603_1608Metric; LCSC C25805
R4: 15K; R_0603_1608Metric; LCSC C22809
R5: 100R; R_0402_1005Metric; LCSC C25076
RN1, RN2, RN3: 220R; R_Array_Concave_4x0402; LCSC C326868
U1: MT2492; SOT-23-6; LCSC C89358

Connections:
+5V: C3.1, L1.2, R3.1, R5.1, RN1.1 (R1.1), RN1.2 (R2.1), RN1.3 (R3.1), RN1.4 (R4.1), RN2.1 (R1.1), RN2.2 (R2.1), RN2.3 (R3.1), RN2.4 (R4.1), RN3.1 (R1.1), RN3.2 (R2.1), RN3.3 (R3.1), RN3.4 (R4.1)
/AUX1: D3.1 (K), J4.11
/AUX2: D4.1 (K), J4.12
/AUX3: J4.21, J6.1, Q1.1 (B)
/AUX4: J4.20, J6.2, Q2.1 (B)
/AUX5: D7.1 (K), J4.16
/AUX6: D8.1 (K), J4.15
/AUX7: D9.1 (K), J4.14
/AUX8: D10.1 (K), J4.13
/AUX10: J4.19, J6.3, Q3.1 (B)
/AUX11: J4.24, J6.4, Q4.1 (B)
/AUX12: J4.23, J6.5, Q5.1 (B)
/CAP+: J3.1, J4.8
/D+: J1.1, J4.2, P1.A6 (D+), P1.B6 (D+)
/D-: J1.2, J4.1, P1.A7 (D-), P1.B7 (D-)
/LAMP_FRONT: D1.1 (K), J4.9
/LAMP_REAR: D2.1 (K), J4.10
/MOTOR_A: J4.6, J4.7, J7.1
/MOTOR_B: J4.4, J4.5, J7.2
/SW: C2.2, L1.1, U1.6 (SW)
/TRACK_LEFT: J4.X1A, J4.X1B, J5.1
/TRACK_RIGHT: J4.X2A, J4.X2B, J5.2
GND: C1.2, C3.2, J2.2, J2.4, J3.2, J4.3, J4.22, P1.A1 (GND), P1.A12 (GND), P1.B1 (GND), P1.B12 (GND), P1.S1 (SHIELD), Q1.2 (E), Q2.2 (E), Q3.2 (E), Q4.2 (E), Q5.2 (E), R1.2, R2.1, R4.2, U1.2 (GND)
unnamed: D1.2 (A), RN1.5 (R4.2)
unnamed: D2.2 (A), RN1.6 (R3.2)
unnamed: D3.2 (A), RN1.7 (R2.2)
unnamed: D4.2 (A), RN1.8 (R1.2)
unnamed: D5.2 (A), RN2.5 (R4.2)
unnamed: D5.1 (K), Q1.3 (C)
unnamed: D6.2 (A), RN2.6 (R3.2)
unnamed: D6.1 (K), Q2.3 (C)
unnamed: D7.2 (A), RN2.7 (R2.2)
unnamed: D8.2 (A), RN2.8 (R1.2)
unnamed: D9.2 (A), RN3.8 (R1.2)
unnamed: D10.2 (A), RN3.7 (R2.2)
unnamed: D11.2 (A), RN3.6 (R3.2)
unnamed: D11.1 (K), Q3.3 (C)
unnamed: D12.2 (A), RN3.5 (R4.2)
unnamed: D12.1 (K), Q4.3 (C)
unnamed: D14.2 (A), R5.2
unnamed: D14.1 (K), Q5.3 (C)
unnamed: P1.A5 (CC1), R1.1
unnamed: P1.B5 (CC2), R2.2
unnamed: C2.1, U1.1 (BS)
unnamed: R3.2, R4.1, U1.3 (FB)
VBUS: D13.2 (A), P1.A4 (VBUS), P1.A9 (VBUS), P1.B4 (VBUS), P1.B9 (VBUS)
VCC: J2.3, J4.18
VDC: C1.1, D13.1 (K), J2.1, J4.17, U1.4 (EN), U1.5 (VIN)

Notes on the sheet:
Function Test Lights
Breakout Headers
E24 Connector
Power Supply
USB Connector

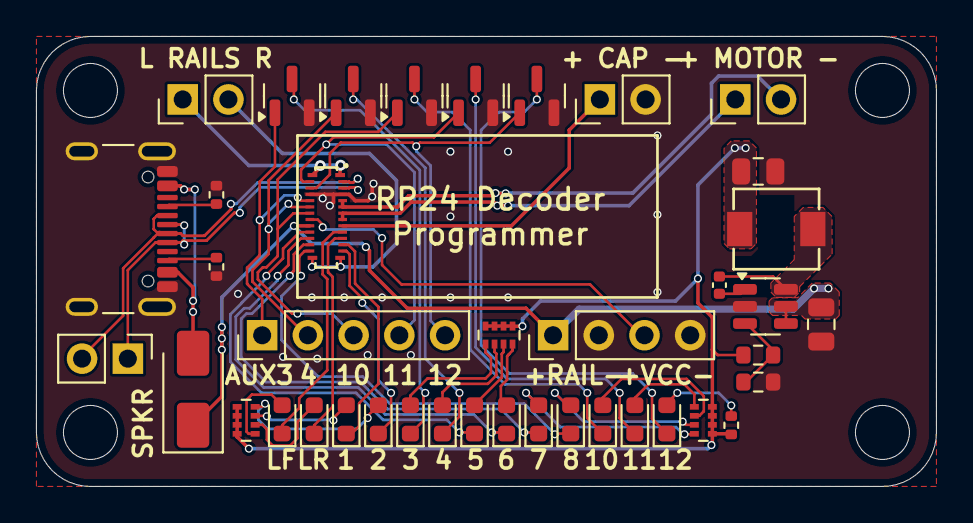
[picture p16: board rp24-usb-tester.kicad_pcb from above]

Board: 2 copper layers, 50.0 x 25.0 mm, 40 parts (0 on the bottom side), 48 nets.

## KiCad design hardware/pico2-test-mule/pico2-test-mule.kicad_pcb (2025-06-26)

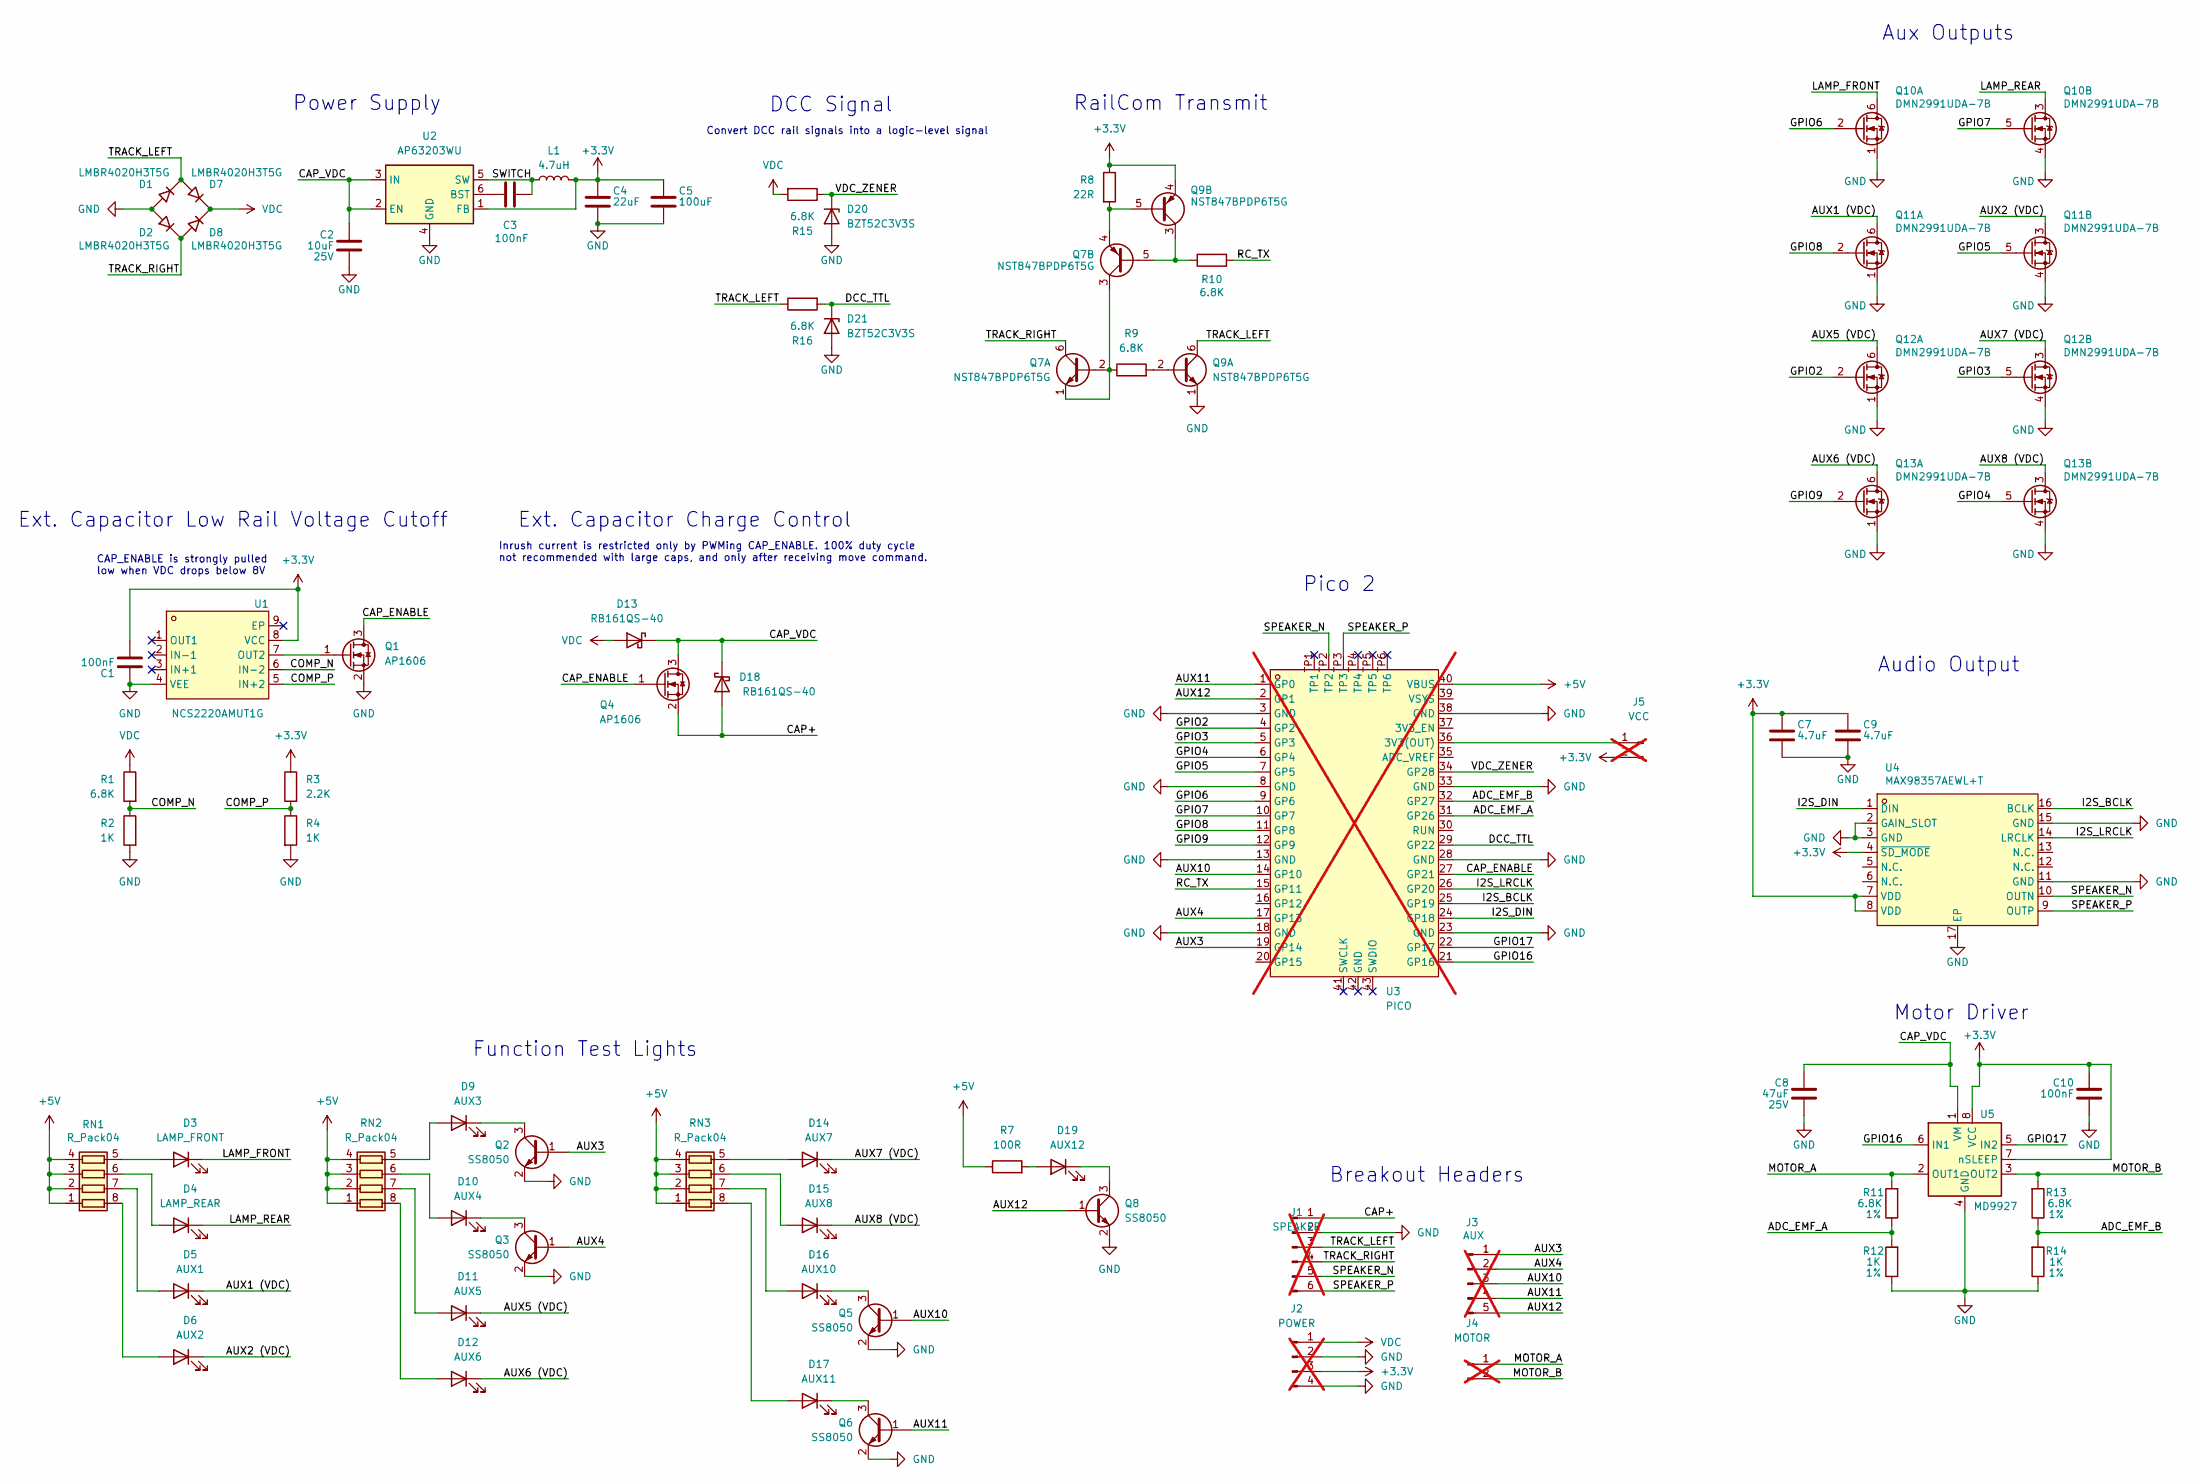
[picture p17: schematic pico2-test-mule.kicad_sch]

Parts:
C1, C3, C10: 100nF; C_0402_1005Metric; LCSC C1525
C2: 10uF; C_0603_1608Metric; Voltage 25V; LCSC C96446
C4: 22uF; C_0603_1608Metric; LCSC C86295
C5: 100uF; C_1206_3216Metric; LCSC C15008
C7, C9: 4.7uF; C_0402_1005Metric; LCSC C307423
C8: 47uF; C_1206_3216Metric; Voltage 25V; LCSC C22367835
D1, D2, D7, D8: LMBR4020H3T5G; U-DFN1608-2_L1.6-W0.8-RD; LCSC C2852608
D3: LAMP_FRONT; LED_0603_1608Metric; LCSC C2290
D4: LAMP_REAR; LED_0603_1608Metric; LCSC C2290
D5: AUX1; LED_0603_1608Metric; LCSC C2290
D6: AUX2; LED_0603_1608Metric; LCSC C2290
D9: AUX3; LED_0603_1608Metric; LCSC C2290
D10: AUX4; LED_0603_1608Metric; LCSC C2290
D11: AUX5; LED_0603_1608Metric; LCSC C2290
D12: AUX6; LED_0603_1608Metric; LCSC C2290
D13, D18: RB161QS-40; DIO-SMD_L1.0-W0.6-P0.65-RD; LCSC C5563750
D14: AUX7; LED_0603_1608Metric; LCSC C2290
D15: AUX8; LED_0603_1608Metric; LCSC C2290
D16: AUX10; LED_0603_1608Metric; LCSC C2290
D17: AUX11; LED_0603_1608Metric; LCSC C2290
D19: AUX12; LED_0603_1608Metric; LCSC C2290
D20, D21: BZT52C3V3S; D_SOD-323; LCSC C19077437
J1: SPEAKER; PinHeader_1x06_P2.54mm_Vertical; not fitted
J2: POWER; PinHeader_1x04_P2.54mm_Vertical; not fitted
J3: AUX; PinHeader_1x05_P2.54mm_Vertical; not fitted
J4: MOTOR; PinHeader_1x02_P2.54mm_Vertical; not fitted
J5: VCC; PinHeader_1x02_P2.54mm_Vertical; not fitted
L1: 4.7uH; IND-SMD_L2.5-W2.0-VLS252012CX-150M; LCSC C5832360
Q1, Q4: AP1606; Diodes_DFN1006-3; LCSC C2849580
Q2, Q3, Q5, Q6, Q8: SS8050; SOT-23; LCSC C2150
Q7, Q9: NST847BPDP6T5G; SOT-963; LCSC C896443
Q10, Q11, Q12, Q13: DMN2991UDA-7B; X2-DFN0806-6_L0.8-W0.6_X2-DFN0806-6; LCSC C2937136
R1, R9, R10, R15, R16: 6.8K; R_0402_1005Metric; LCSC C25944
R2, R4: 1K; R_0402_1005Metric; LCSC C11702
R3: 2.2K; R_0402_1005Metric; LCSC C25879
R7: 100R; R_0402_1005Metric; LCSC C25076
R8: 22R; R_0402_1005Metric; LCSC C25092
R11, R13: 6.8K; R_0402_1005Metric; Tolerance 1%; LCSC C25944
R12, R14: 1K; R_0402_1005Metric; Tolerance 1%; LCSC C11702
RN1, RN2, RN3: R_Pack04; R_Array_Concave_4x0402; LCSC C48442
U1: NCS2220AMUT1G; DFN-8_L1.6-W1.6-P0.40-BL-EP; LCSC C464059
U2: AP63203WU; TSOT-26_L2.9-W1.6-P0.95-LS2.8-BL; LCSC C780769
U3: PICO; RaspberryPi_Pico_Common_THT; not fitted
U4: MAX98357AEWL+T; TQFN-16_L3.0-W3.0-P0.50-BL-EP1.5; LCSC C910544
U5: MD9927; WDFN-8_L2.0-W2.0-P0.50-BL-EP; LCSC C2684662

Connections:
+3.3V: C1.2, C4.1, C5.1, C7.1, C9.1, C10.1, J2.3, J5.2, L1.2, Q9.4 (E2), R3.1, R8.1, U1.8 (VCC), U2.1 (FB), U4.4 (~SD_MODE), U4.7 (VDD), U4.8 (VDD), U5.7 (nSLEEP), U5.8 (VCC)
+5V: R7.1, RN1.1 (R1.1), RN1.2 (R2.1), RN1.3 (R3.1), RN1.4 (R4.1), RN2.1 (R1.1), RN2.2 (R2.1), RN2.3 (R3.1), RN2.4 (R4.1), RN3.1 (R1.1), RN3.2 (R2.1), RN3.3 (R3.1), RN3.4 (R4.1), U3.40 (VBUS)
/ADC_EMF_A: R11.1, R12.2, U3.31 (GP26)
/ADC_EMF_B: R13.1, R14.2, U3.32 (GP27)
/AUX1 (VDC): D5.1 (K), Q11.6 (D1)
/AUX2 (VDC): D6.1 (K), Q11.3 (D2)
/AUX3: J3.1, Q2.1 (B), U3.19 (GP14)
/AUX4: J3.2, Q3.1 (B), U3.17 (GP13)
/AUX5 (VDC): D11.1 (K), Q12.6 (D1)
/AUX6 (VDC): D12.1 (K), Q13.6 (D1)
/AUX7 (VDC): D14.1 (K), Q12.3 (D2)
/AUX8 (VDC): D15.1 (K), Q13.3 (D2)
/AUX10: J3.3, Q5.1 (B), U3.14 (GP10)
/AUX11: J3.4, Q6.1 (B), U3.1 (GP0)
/AUX12: J3.5, Q8.1 (B), U3.2 (GP1)
/CAP+: D18.2 (A), J1.1, Q4.2 (S)
/CAP_ENABLE: Q1.3 (D), Q4.1 (G), U3.27 (GP21)
/CAP_VDC: C2.1, C8.1, D13.1 (K), D18.1 (K), Q4.3 (D), U2.2 (EN), U2.3 (IN), U5.1 (VM)
/COMP_N: R1.2, R2.1, U1.6 (IN−2)
/COMP_P: R3.2, R4.1, U1.5 (IN+2)
/DCC_TTL: D21.1 (K), R16.2, U3.29 (GP22)
/GPIO2: Q12.2 (G1), U3.4 (GP2)
/GPIO3: Q12.5 (G2), U3.5 (GP3)
/GPIO4: Q13.5 (G2), U3.6 (GP4)
/GPIO5: Q11.5 (G2), U3.7 (GP5)
/GPIO6: Q10.2 (G1), U3.9 (GP6)
/GPIO7: Q10.5 (G2), U3.10 (GP7)
/GPIO8: Q11.2 (G1), U3.11 (GP8)
/GPIO9: Q13.2 (G1), U3.12 (GP9)
/GPIO16: U3.21 (GP16), U5.6 (IN1)
/GPIO17: U3.22 (GP17), U5.5 (IN2)
/I2S_BCLK: U3.25 (GP19), U4.16 (BCLK)
/I2S_DIN: U3.24 (GP18), U4.1 (DIN)
/I2S_LRCLK: U3.26 (GP20), U4.14 (LRCLK)
/LAMP_FRONT: D3.1 (K), Q10.6 (D1)
/LAMP_REAR: D4.1 (K), Q10.3 (D2)
/MOTOR_A: J4.1, R11.2, U5.2 (OUT1)
/MOTOR_B: J4.2, R13.2, U5.3 (OUT2)
/RC_TX: R10.2, U3.15 (GP11)
/SPEAKER_N: J1.5, U3.TP2, U4.10 (OUTN)
/SPEAKER_P: J1.6, U3.TP3, U4.9 (OUTP)
/SWITCH: C3.2, L1.1, U2.5 (SW)
/TRACK_LEFT: D1.1 (K), D7.2 (A), J1.3, Q9.6 (C1), R16.1
/TRACK_RIGHT: D2.1 (K), D8.2 (A), J1.4, Q7.6 (C1)
/VDC_ZENER: D20.1 (K), R15.1, U3.34 (GP28)
GND: C1.1, C2.2, C4.2, C5.2, C7.2, C8.2, C9.2, C10.2, D1.2 (A), D2.2 (A), D20.2 (A), D21.2 (A), J1.2, J2.2, J2.4, Q1.2 (S), Q2.2 (E), Q3.2 (E), Q5.2 (E), Q6.2 (E), Q8.2 (E), Q9.1 (E1), Q10.1 (S1), Q10.4 (S2), Q11.1 (S1), Q11.4 (S2), Q12.1 (S1), Q12.4 (S2), Q13.1 (S1), Q13.4 (S2), R2.2, R4.2, R12.1, R14.1, U1.4 (VEE), U2.4 (GND), U3.3 (GND), U3.8 (GND), U3.13 (GND), U3.18 (GND), U3.23 (GND), U3.28 (GND), U3.33 (GND), U3.38 (GND), U4.2 (GAIN_SLOT), U4.3 (GND), U4.11 (GND), U4.15 (GND), U4.17 (EP), U5.4 (GND), U5.9 (GND)
unnamed: D3.2 (A), RN1.5 (R4.2)
unnamed: D4.2 (A), RN1.6 (R3.2)
unnamed: D5.2 (A), RN1.7 (R2.2)
unnamed: D6.2 (A), RN1.8 (R1.2)
unnamed: D9.2 (A), RN2.5 (R4.2)
unnamed: D9.1 (K), Q2.3 (C)
unnamed: D10.2 (A), RN2.6 (R3.2)
unnamed: D10.1 (K), Q3.3 (C)
unnamed: D11.2 (A), RN2.7 (R2.2)
unnamed: D12.2 (A), RN2.8 (R1.2)
unnamed: D14.2 (A), RN3.5 (R4.2)
unnamed: D15.2 (A), RN3.6 (R3.2)
unnamed: D16.2 (A), RN3.7 (R2.2)
unnamed: D16.1 (K), Q5.3 (C)
unnamed: D17.2 (A), RN3.8 (R1.2)
unnamed: D17.1 (K), Q6.3 (C)
unnamed: D19.2 (A), R7.2
unnamed: D19.1 (K), Q8.3 (C)
unnamed: J5.1, U3.36 (3V3(OUT))
unnamed: Q1.1 (G), U1.7 (OUT2)
unnamed: Q7.1 (E1), Q7.2 (B1), Q7.3 (C2), R9.1
unnamed: Q7.5 (B2), Q9.3 (C2), R10.1
unnamed: Q7.4 (E2), Q9.5 (B2), R8.2
unnamed: Q9.2 (B1), R9.2
unnamed: C3.1, U2.6 (BST)
VDC: D7.1 (K), D8.1 (K), D13.2 (A), J2.1, R1.1, R15.2

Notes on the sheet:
Motor Driver
Ext. Capacitor Charge Control
Convert DCC rail signals into a logic-level signal
Audio Output
RailCom Transmit
DCC Signal
Aux Outputs
Function Test Lights
Ext. Capacitor Low Rail Voltage Cutoff
Power Supply
Pico 2
CAP_ENABLE is strongly pulled low when VDC drops below 8V
Inrush current is restricted only by PWMing CAP_ENABLE. 100% duty cycle not recommended with large caps, and only after receiving move command.
Breakout Headers

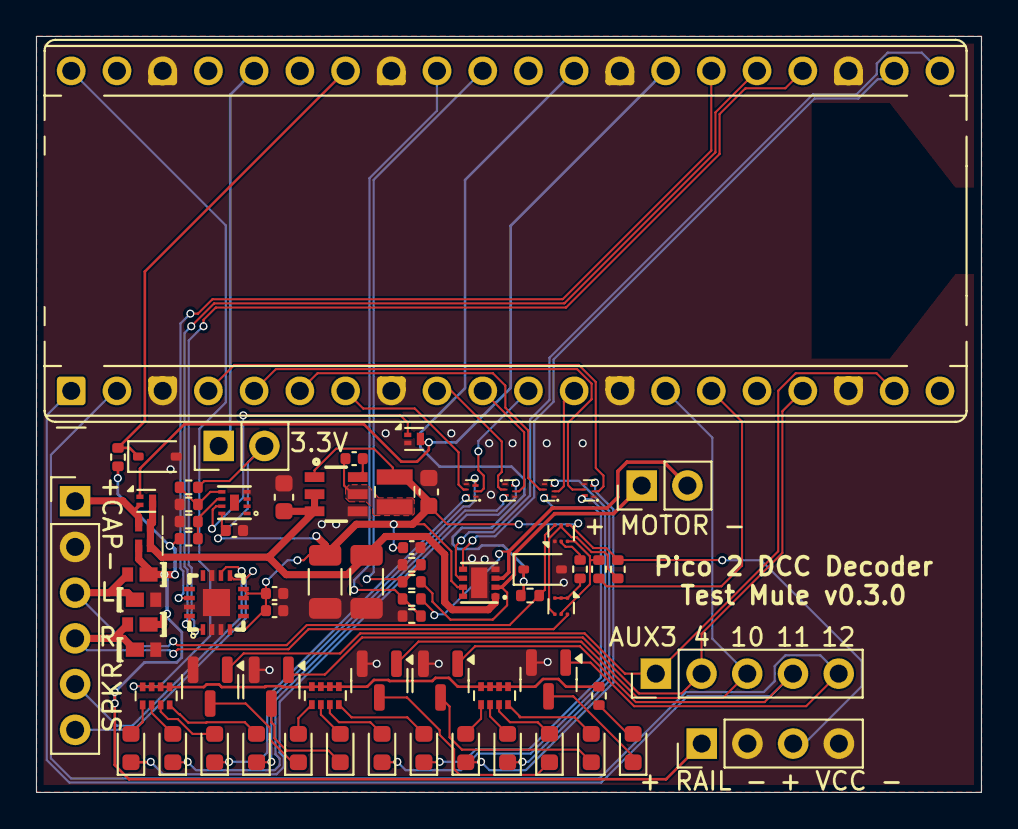
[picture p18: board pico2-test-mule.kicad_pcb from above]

Board: 2 copper layers, 52.5 x 42.0 mm, 71 parts (0 on the bottom side), 72 nets.

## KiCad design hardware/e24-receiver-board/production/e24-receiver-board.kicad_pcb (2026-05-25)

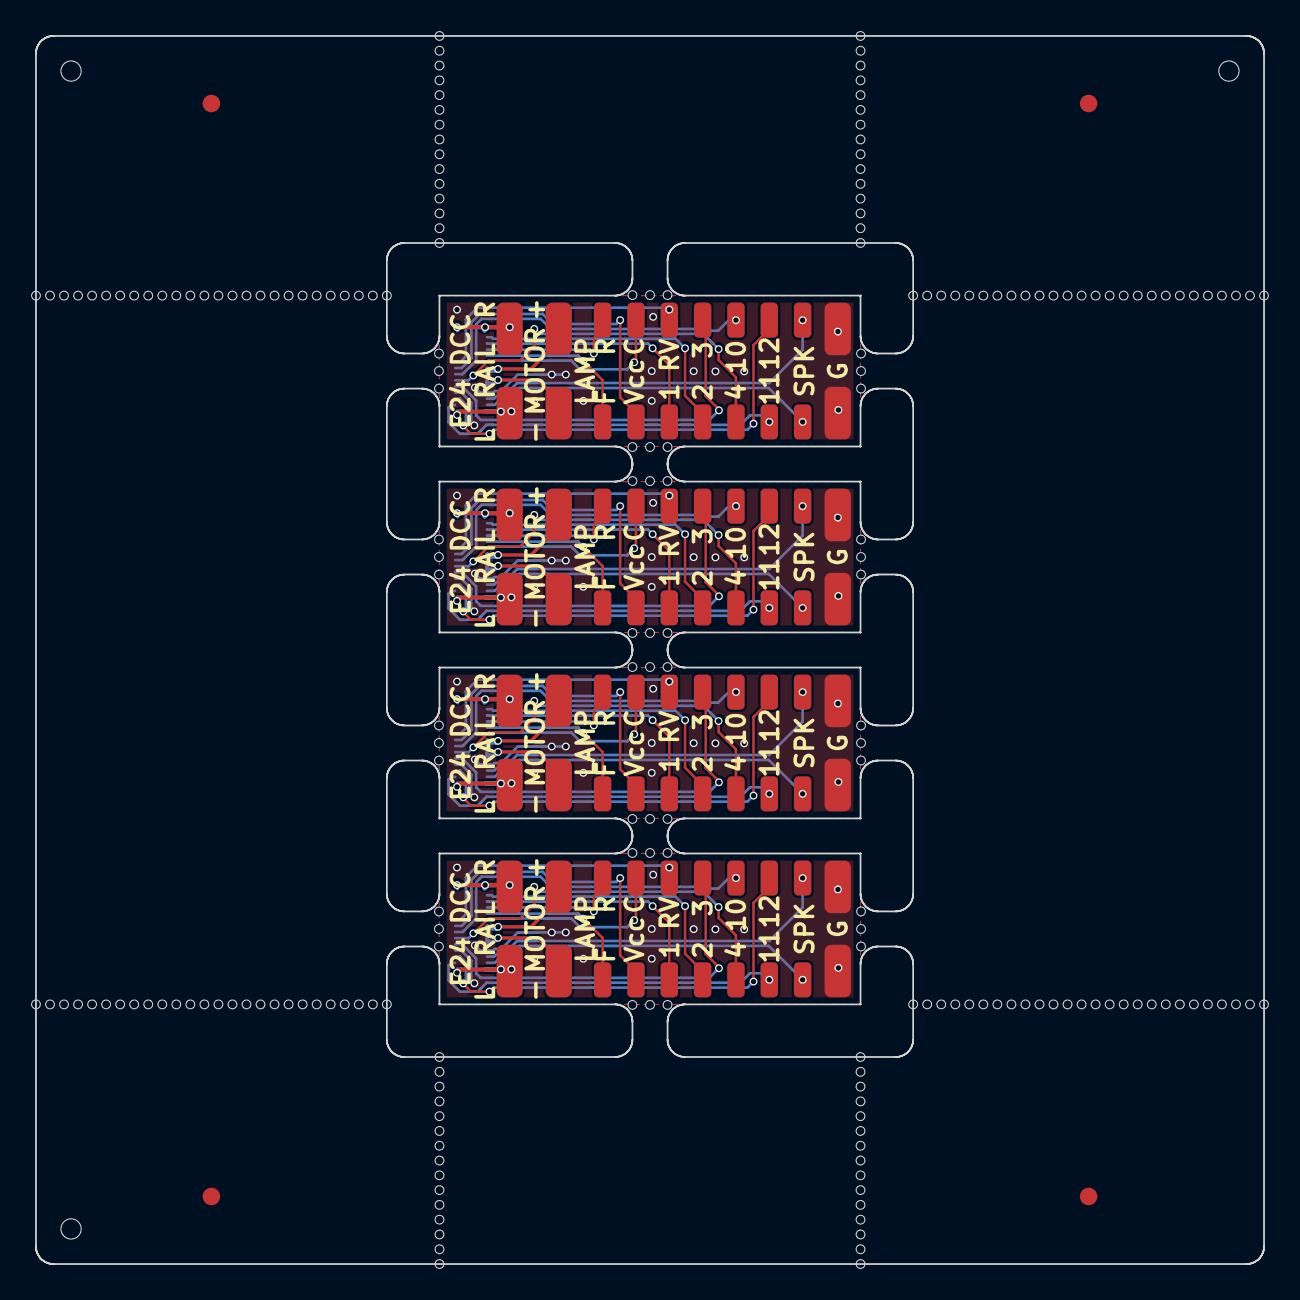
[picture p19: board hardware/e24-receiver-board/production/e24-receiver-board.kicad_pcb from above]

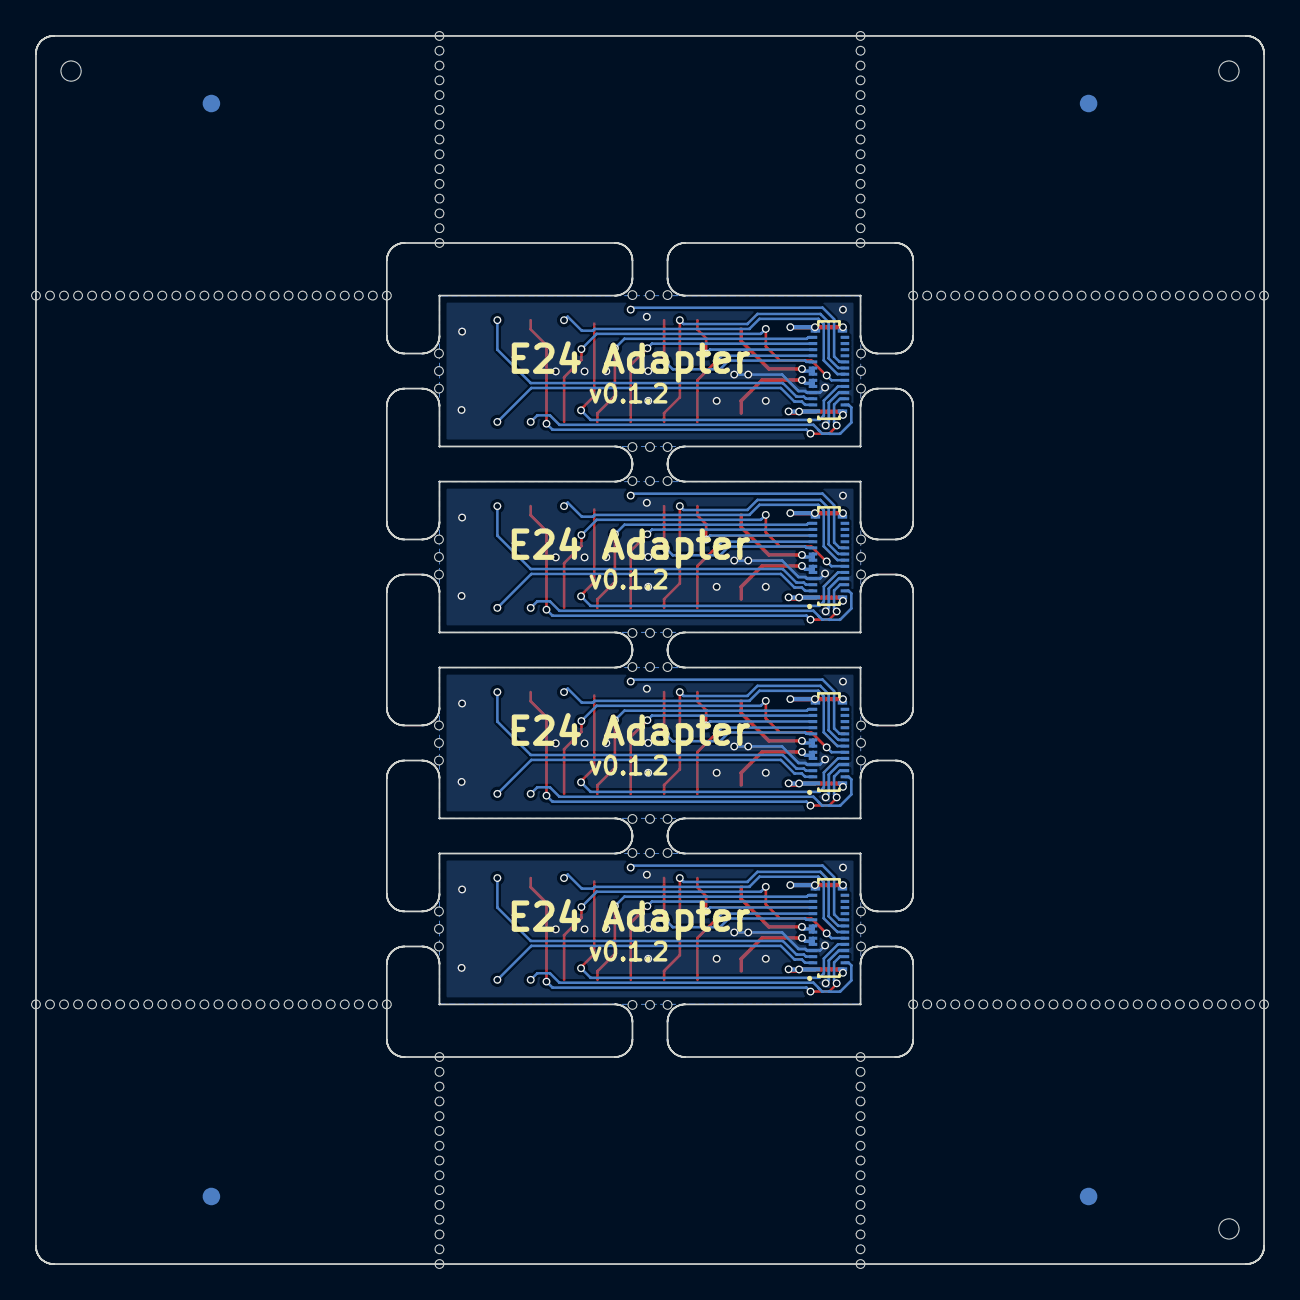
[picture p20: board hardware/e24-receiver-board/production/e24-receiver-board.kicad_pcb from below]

Board: 2 copper layers, 70.0 x 70.0 mm, 307 parts (8 on the bottom side), 76 nets.

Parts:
J1, J1#2, J1#3, J1#4: 505070-2422; CONN-SMD_24P-P0.35_5050702422
J2, J2#2, J2#3, J2#4: TRACK_LEFT; SolderWirePad_1x01_SMD_1.5x3mm
J3, J3#2, J3#3, J3#4: MOTOR-; SolderWirePad_1x01_SMD_1.5x3mm
J4, J4#2, J4#3, J4#4: LAMP_FRONT; SolderWirePad_1x01_SMD_1x2mm
J5, J5#2, J5#3, J5#4: VCC; SolderWirePad_1x01_SMD_1x2mm
J6, J6#2, J6#3, J6#4: AUX1; SolderWirePad_1x01_SMD_1x2mm
J7, J7#2, J7#3, J7#4: AUX2; SolderWirePad_1x01_SMD_1x2mm
J8, J8#2, J8#3, J8#4: AUX4; SolderWirePad_1x01_SMD_1x2mm
J9, J9#2, J9#3, J9#4: AUX11; SolderWirePad_1x01_SMD_1x2mm
J10, J10#2, J10#3, J10#4: SPEAKER-; SolderWirePad_1x01_SMD_1x2mm
J11, J11#2, J11#3, J11#4: GND1; SolderWirePad_1x01_SMD_1.5x3mm
J12, J12#2, J12#3, J12#4: TRACK_RIGHT; SolderWirePad_1x01_SMD_1.5x3mm
J13, J13#2, J13#3, J13#4: MOTOR+; SolderWirePad_1x01_SMD_1.5x3mm
J14, J14#2, J14#3, J14#4: LAMP_REAR; SolderWirePad_1x01_SMD_1x2mm
J15, J15#2, J15#3, J15#4: CAP+; SolderWirePad_1x01_SMD_1x2mm
J16, J16#2, J16#3, J16#4: U+; SolderWirePad_1x01_SMD_1x2mm
J17, J17#2, J17#3, J17#4: AUX3; SolderWirePad_1x01_SMD_1x2mm
J18, J18#2, J18#3, J18#4: AUX10; SolderWirePad_1x01_SMD_1x2mm
J19, J19#2, J19#3, J19#4: AUX12; SolderWirePad_1x01_SMD_1x2mm
J20, J20#2, J20#3, J20#4: SPEAKER+; SolderWirePad_1x01_SMD_1x2mm
J21, J21#2, J21#3, J21#4: GND2; SolderWirePad_1x01_SMD_1.5x3mm
KiKit_FID_B_1, KiKit_FID_B_2, KiKit_FID_B_3, KiKit_FID_B_4: Fiducial
KiKit_FID_T_1, KiKit_FID_T_2, KiKit_FID_T_3, KiKit_FID_T_4: Fiducial
KiKit_MB_1_1, KiKit_MB_1_2, KiKit_MB_1_3, KiKit_MB_2_1, KiKit_MB_2_2, KiKit_MB_2_3, KiKit_MB_3_1, KiKit_MB_3_2, KiKit_MB_3_3, KiKit_MB_4_1, KiKit_MB_4_2, KiKit_MB_4_3, KiKit_MB_5_1, KiKit_MB_5_2, KiKit_MB_5_3, KiKit_MB_6_1, KiKit_MB_6_2, KiKit_MB_6_3, KiKit_MB_7_1, KiKit_MB_7_2, KiKit_MB_7_3, KiKit_MB_8_1, KiKit_MB_8_2, KiKit_MB_8_3, KiKit_MB_9_1, KiKit_MB_9_2, KiKit_MB_9_3, KiKit_MB_10_1, KiKit_MB_10_2, KiKit_MB_10_3, KiKit_MB_11_1, KiKit_MB_11_2, KiKit_MB_11_3, KiKit_MB_12_1, KiKit_MB_12_2, KiKit_MB_12_3, KiKit_MB_13_1, KiKit_MB_13_2, KiKit_MB_13_3, KiKit_MB_14_1, KiKit_MB_14_2, KiKit_MB_14_3, KiKit_MB_15_1, KiKit_MB_15_2, KiKit_MB_15_3, KiKit_MB_16_1, KiKit_MB_16_2, KiKit_MB_16_3, KiKit_MB_17_1, KiKit_MB_17_2, KiKit_MB_17_3, KiKit_MB_17_4, KiKit_MB_17_5, KiKit_MB_17_6, KiKit_MB_17_7, KiKit_MB_17_8, KiKit_MB_17_9, KiKit_MB_17_10, KiKit_MB_17_11, KiKit_MB_17_12, KiKit_MB_17_13, KiKit_MB_17_14, KiKit_MB_17_15, KiKit_MB_18_1, KiKit_MB_18_2, KiKit_MB_18_3, KiKit_MB_18_4, KiKit_MB_18_5, KiKit_MB_18_6, KiKit_MB_18_7, KiKit_MB_18_8, KiKit_MB_18_9, KiKit_MB_18_10, KiKit_MB_18_11, KiKit_MB_18_12, KiKit_MB_18_13, KiKit_MB_18_14, KiKit_MB_18_15, KiKit_MB_19_1, KiKit_MB_19_2, KiKit_MB_19_3, KiKit_MB_19_4, KiKit_MB_19_5, KiKit_MB_19_6, KiKit_MB_19_7, KiKit_MB_19_8, KiKit_MB_19_9, KiKit_MB_19_10, KiKit_MB_19_11, KiKit_MB_19_12, KiKit_MB_19_13, KiKit_MB_19_14, KiKit_MB_19_15, KiKit_MB_20_1, KiKit_MB_20_2, KiKit_MB_20_3, KiKit_MB_20_4, KiKit_MB_20_5, KiKit_MB_20_6, KiKit_MB_20_7, KiKit_MB_20_8, KiKit_MB_20_9, KiKit_MB_20_10, KiKit_MB_20_11, KiKit_MB_20_12, KiKit_MB_20_13, KiKit_MB_20_14, KiKit_MB_20_15, KiKit_MB_21_1, KiKit_MB_21_2, KiKit_MB_21_3, KiKit_MB_21_4, KiKit_MB_21_5, KiKit_MB_21_6, KiKit_MB_21_7, KiKit_MB_21_8, KiKit_MB_21_9, KiKit_MB_21_10, KiKit_MB_21_11, KiKit_MB_21_12, KiKit_MB_21_13, KiKit_MB_21_14, KiKit_MB_21_15, KiKit_MB_21_16, KiKit_MB_21_17, KiKit_MB_21_18, KiKit_MB_21_19, KiKit_MB_21_20, KiKit_MB_21_21, KiKit_MB_21_22, KiKit_MB_21_23, KiKit_MB_21_24, KiKit_MB_21_25, KiKit_MB_21_26, KiKit_MB_22_1, KiKit_MB_22_2, KiKit_MB_22_3, KiKit_MB_22_4, KiKit_MB_22_5, KiKit_MB_22_6, KiKit_MB_22_7, KiKit_MB_22_8, KiKit_MB_22_9, KiKit_MB_22_10, KiKit_MB_22_11, KiKit_MB_22_12, KiKit_MB_22_13, KiKit_MB_22_14, KiKit_MB_22_15, KiKit_MB_22_16, KiKit_MB_22_17, KiKit_MB_22_18, KiKit_MB_22_19, KiKit_MB_22_20, KiKit_MB_22_21, KiKit_MB_22_22, KiKit_MB_22_23, KiKit_MB_22_24, KiKit_MB_22_25, KiKit_MB_22_26, KiKit_MB_23_1, KiKit_MB_23_2, KiKit_MB_23_3, KiKit_MB_23_4, KiKit_MB_23_5, KiKit_MB_23_6, KiKit_MB_23_7, KiKit_MB_23_8, KiKit_MB_23_9, KiKit_MB_23_10, KiKit_MB_23_11, KiKit_MB_23_12, KiKit_MB_23_13, KiKit_MB_23_14, KiKit_MB_23_15, KiKit_MB_23_16, KiKit_MB_23_17, KiKit_MB_23_18, KiKit_MB_23_19, KiKit_MB_23_20, KiKit_MB_23_21, KiKit_MB_23_22, KiKit_MB_23_23, KiKit_MB_23_24, KiKit_MB_23_25, KiKit_MB_23_26, KiKit_MB_24_1, KiKit_MB_24_2, KiKit_MB_24_3, KiKit_MB_24_4, KiKit_MB_24_5, KiKit_MB_24_6, KiKit_MB_24_7, KiKit_MB_24_8, KiKit_MB_24_9, KiKit_MB_24_10, KiKit_MB_24_11, KiKit_MB_24_12, KiKit_MB_24_13, KiKit_MB_24_14, KiKit_MB_24_15, KiKit_MB_24_16, KiKit_MB_24_17, KiKit_MB_24_18, KiKit_MB_24_19, KiKit_MB_24_20, KiKit_MB_24_21, KiKit_MB_24_22, KiKit_MB_24_23, KiKit_MB_24_24, KiKit_MB_24_25, KiKit_MB_24_26: NPTH
KiKit_TO_1, KiKit_TO_2, KiKit_TO_3: NPTH

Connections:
Board_0-/AUX1 (VDC): J1#4.11, J6.1
Board_0-/AUX2 (VDC): J1#4.12, J7#3.1
Board_0-/AUX3: J1#4.21, J17.1
Board_0-/AUX4: J1#4.20, J8#3.1
Board_0-/AUX10: J1#4.19, J18#3.1
Board_0-/AUX11: J1#4.24, J9#4.1
Board_0-/AUX12: J1#4.23, J19#3.1
Board_0-/CAP+: J1#4.8, J15#2.1
Board_0-/LAMP_FRONT: J1#4.9, J4#3.1
Board_0-/LAMP_REAR: J1#4.10, J14.1
Board_0-/MOTOR_A: J1#4.6, J1#4.7, J13#3.1
Board_0-/MOTOR_B: J1#4.4, J1#4.5, J3#2.1
Board_0-/SPEAKER_N: J1#4.1, J10#3.1
Board_0-/SPEAKER_P: J1#4.2, J20#3.1
Board_0-/TRACK_LEFT: J1#4.X1A, J1#4.X1B, J2.1
Board_0-/TRACK_RIGHT: J1#4.X2A, J1#4.X2B, J12.1
Board_0-GND: J1#4.3, J1#4.22, J11#4.1, J21#3.1
Board_0-VCC: J1#4.18, J5#4.1
Board_0-VDC: J1#4.17, J16.1
Board_1-/AUX1 (VDC): J1#3.11, J6#3.1
Board_1-/AUX2 (VDC): J1#3.12, J7#4.1
Board_1-/AUX3: J1#3.21, J17#2.1
Board_1-/AUX4: J1#3.20, J8#2.1
Board_1-/AUX10: J1#3.19, J18#2.1
Board_1-/AUX11: J1#3.24, J9#2.1
Board_1-/AUX12: J1#3.23, J19#4.1
Board_1-/CAP+: J1#3.8, J15#4.1
Board_1-/LAMP_FRONT: J1#3.9, J4#4.1
Board_1-/LAMP_REAR: J1#3.10, J14#2.1
Board_1-/MOTOR_A: J1#3.6, J1#3.7, J13.1
Board_1-/MOTOR_B: J1#3.4, J1#3.5, J3#3.1
Board_1-/SPEAKER_N: J1#3.1, J10#4.1
Board_1-/SPEAKER_P: J1#3.2, J20.1
Board_1-/TRACK_LEFT: J1#3.X1A, J1#3.X1B, J2#4.1
Board_1-/TRACK_RIGHT: J1#3.X2A, J1#3.X2B, J12#4.1
Board_1-GND: J1#3.3, J1#3.22, J11.1, J21.1
Board_1-VCC: J1#3.18, J5#3.1
Board_1-VDC: J1#3.17, J16#2.1
Board_2-/AUX1 (VDC): J1.11, J6#4.1
Board_2-/AUX2 (VDC): J1.12, J7#2.1
Board_2-/AUX3: J1.21, J17#4.1
Board_2-/AUX4: J1.20, J8#4.1
Board_2-/AUX10: J1.19, J18#4.1
Board_2-/AUX11: J1.24, J9.1
Board_2-/AUX12: J1.23, J19.1
Board_2-/CAP+: J1.8, J15#3.1
Board_2-/LAMP_FRONT: J1.9, J4#2.1
Board_2-/LAMP_REAR: J1.10, J14#3.1
Board_2-/MOTOR_A: J1.6, J1.7, J13#4.1
Board_2-/MOTOR_B: J1.4, J1.5, J3#4.1
Board_2-/SPEAKER_N: J1.1, J10#2.1
Board_2-/SPEAKER_P: J1.2, J20#4.1
Board_2-/TRACK_LEFT: J1.X1A, J1.X1B, J2#3.1
Board_2-/TRACK_RIGHT: J1.X2A, J1.X2B, J12#3.1
Board_2-GND: J1.3, J1.22, J11#2.1, J21#4.1
Board_2-VCC: J1.18, J5.1
Board_2-VDC: J1.17, J16#3.1
Board_3-/AUX1 (VDC): J1#2.11, J6#2.1
Board_3-/AUX2 (VDC): J1#2.12, J7.1
Board_3-/AUX3: J1#2.21, J17#3.1
Board_3-/AUX4: J1#2.20, J8.1
Board_3-/AUX10: J1#2.19, J18.1
Board_3-/AUX11: J1#2.24, J9#3.1
Board_3-/AUX12: J1#2.23, J19#2.1
Board_3-/CAP+: J1#2.8, J15.1
Board_3-/LAMP_FRONT: J1#2.9, J4.1
Board_3-/LAMP_REAR: J1#2.10, J14#4.1
Board_3-/MOTOR_A: J1#2.6, J1#2.7, J13#2.1
Board_3-/MOTOR_B: J1#2.4, J1#2.5, J3.1
Board_3-/SPEAKER_N: J1#2.1, J10.1
Board_3-/SPEAKER_P: J1#2.2, J20#2.1
Board_3-/TRACK_LEFT: J1#2.X1A, J1#2.X1B, J2#2.1
Board_3-/TRACK_RIGHT: J1#2.X2A, J1#2.X2B, J12#2.1
Board_3-GND: J1#2.3, J1#2.22, J11#3.1, J21#2.1
Board_3-VCC: J1#2.18, J5#2.1
Board_3-VDC: J1#2.17, J16#4.1

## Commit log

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2025-01-11 feat: move usb port to avoid shorting rails
    [panel-CmtUser.gbr, panel-CuBottom.gbl, panel-CuTop.gtl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]
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2025-01-16 feat: upgrade flash to 8MB
    feat: reorganize layout to be cleaner
    [W25Q64JWBYIQ_TR.stp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]
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2025-01-20 fix: dfm fixes and trace cleanup
    [panel-CmtUser.gbr, panel-CuBottom.gbl, panel-CuTop.gtl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]
2025-01-20 fix: allow cap to discharge below 8V rail voltage
    [panel-CmtUser.gbr, panel-CuBottom.gbl, panel-CuTop.gtl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]
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2025-01-20 fix: update footprints and component rotations
    [W25Q64JWBYIQ_TR.stp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]
2025-01-20 fix: more dfm fixes
    [panel-CmtUser.gbr, panel-CuBottom.gbl, panel-CuTop.gtl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]
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2025-01-20 fix: make boot button easier to press
    fix: dfm fixes
    [panel-CmtUser.gbr, panel-CuBottom.gbl, panel-CuTop.gtl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]
2025-01-23 fix: shrink usb differential traces
    [panel-CmtUser.gbr, panel-CuBottom.gbl, panel-CuTop.gtl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]
2025-01-23 fix: switch button type
    [panel-CmtUser.gbr, panel-CuBottom.gbl, panel-CuTop.gtl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]
2025-01-23 fix: convert 0.2mm vias to 0.3mm
    [panel-CmtUser.gbr, panel-CuBottom.gbl, panel-CuTop.gtl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]
2025-01-25 fix: space out higher power terminals
    [e24-receiver-board.kicad_pcb, e24-receiver-board.kicad_sch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]
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2025-01-26 fix: reduce unique part count
    [panel-CmtUser.gbr, panel-CuBottom.gbl, panel-CuTop.gtl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]
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2025-02-13 chore: remove broken rp2040 design
    [505066-2422.stp, MAX98357AEWL+T.stp, NSR1030QMUTWG.stp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]
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2025-02-15 feat: add new pico2 test mule for firmware dev
    [pico2-test-mule-CmtUser.gbr, pico2-test-mule-CuBottom.gbl, pico2-test-mule-CuTop.gtl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]
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2025-02-16 chore: rearrange i2s pins for easier pio use
    [rp2350-decoder.kicad_pcb, rp2350-decoder.kicad_sch]
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2025-02-16 chore: increase bootsel resistance
    chore: add missing heights
    [rp2350-decoder.kicad_pcb, rp2350-decoder.kicad_sch]
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2025-02-16 chore(main): release rp24-usb-tester 0.3.0 (#4)
    * chore(main): release rp24-usb-tester 0.3.0
    * chore: update KiCad revisions
    ---------
    [rp24-usb-tester.kicad_pcb, rp24-usb-tester.kicad_sch]
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2025-02-16 chore(main): release pico2-test-mule 0.2.0 (#2)
    * chore(main): release pico2-test-mule 0.2.0
    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
    [pico2-test-mule.kicad_pcb, pico2-test-mule.kicad_sch]
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2025-02-19 fix: switch to recommended crystal
    [panel-CmtUser.gbr, panel-CuBottom.gbl, panel-CuTop.gtl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]
2025-02-19 chore(main): release rp2350-decoder 0.0.1 (#11)
    * chore(main): release rp2350-decoder 0.0.1
    * Update .release-please-manifest.json
    * Update CHANGELOG.md
    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
    [rp2350-decoder.kicad_pcb, rp2350-decoder.kicad_sch]
2025-02-21 fix: lower gate voltage to the dcc signal mosfet
    [panel-CmtUser.gbr, panel-CuBottom.gbl, panel-CuTop.gtl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]
2025-02-21 chore(main): release rp2350-decoder 0.0.2 (#12)
    * chore(main): release rp2350-decoder 0.0.2
    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
    [rp2350-decoder.kicad_pcb, rp2350-decoder.kicad_sch]
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2025-02-22 chore: fix footprint script path validation
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2025-02-23 fix: update fonts and update to kicad 9.0
    [rp24-usb-tester-CmtUser.gbr, rp24-usb-tester-CuBottom.gbl, rp24-usb-tester-CuTop.gtl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]
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2025-02-23 chore(main): release rp24-usb-tester 0.3.1 (#14)
    * chore(main): release rp24-usb-tester 0.3.1
    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
    [rp24-usb-tester.kicad_pcb, rp24-usb-tester.kicad_sch]
2025-02-23 fix: update to kicad 9.0
    [pico2-test-mule-CmtUser.gbr, pico2-test-mule-CuBottom.gbl, pico2-test-mule-CuTop.gtl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]
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2025-02-23 chore: ensure panel pcbs don't prevent pcb renders
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2025-02-23 chore(main): release pico2-test-mule 0.2.1 (#18)
    * chore(main): release pico2-test-mule 0.2.1
    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
    [pico2-test-mule.kicad_pcb, pico2-test-mule.kicad_sch]
2025-02-23 chore(main): release e24-receiver-board 0.1.1 (#19)
    * chore(main): release e24-receiver-board 0.1.1
    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
    [e24-receiver-board.kicad_pcb, e24-receiver-board.kicad_sch, panel.kicad_pcb]
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2025-02-23 chore: fix pcb trigger filter
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2025-02-25 chore: fix GPIO label names
    [pico2-test-mule-CmtUser.gbr, pico2-test-mule-CuBottom.gbl, pico2-test-mule-CuTop.gtl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]
2025-02-25 fix: add debounce capacitor to dcc signal gate
    [rp2350-decoder-CmtUser.gbr, rp2350-decoder-CuBottom.gbl, rp2350-decoder-CuTop.gtl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]
2025-02-27 chore(main): release pico2-test-mule 0.2.2 (#21)
    * chore(main): release pico2-test-mule 0.2.2
    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
    [pico2-test-mule.kicad_pcb, pico2-test-mule.kicad_sch]
2025-02-27 fix: update debounce cap value
    [rp2350-decoder.kicad_pcb, rp2350-decoder.kicad_sch]
2025-02-27 chore(main): release rp2350-decoder 0.0.3 (#20)
    * chore(main): release rp2350-decoder 0.0.3
    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
    [rp2350-decoder.kicad_pcb, rp2350-decoder.kicad_sch]
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2025-02-27 fix: combine left side headers
    [pico2-test-mule.kicad_pcb, pico2-test-mule.kicad_sch]
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2025-02-27 fix: minor trace rerouting
    [pico2-test-mule.kicad_pcb]
2025-02-27 chore(main): release pico2-test-mule 0.2.3 (#22)
    * chore(main): release pico2-test-mule 0.2.3
    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
    [pico2-test-mule.kicad_pcb, pico2-test-mule.kicad_sch]
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2025-03-08 fix: reduce DCC_TTL gate voltage
    fix: tweak DCC_TTL debounce cap value
    [pico2-test-mule-CmtUser.gbr, pico2-test-mule-CuBottom.gbl, pico2-test-mule-CuTop.gtl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]
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2025-03-08 chore(main): release pico2-test-mule 0.2.4 (#23)
    * chore(main): release pico2-test-mule 0.2.4
    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
    [pico2-test-mule.kicad_pcb, pico2-test-mule.kicad_sch]
2025-03-08 fix: update DCC_TTL debounce capacitor value
    [rp2350-decoder-CmtUser.gbr, rp2350-decoder-CuBottom.gbl, rp2350-decoder-CuTop.gtl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]
2025-03-08 chore(main): release rp2350-decoder 0.0.4 (#24)
    * chore(main): release rp2350-decoder 0.0.4
    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
    [rp2350-decoder.kicad_pcb, rp2350-decoder.kicad_sch]
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2025-03-14 chore: regenerate gerber files with fixed kikit
    [e24-receiver-board-CmtUser.gbr, e24-receiver-board-CuBottom.gbl, e24-receiver-board-CuTop.gtl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]
2025-03-14 fix: add ground vias near motor driver
    [rp2350-decoder.kicad_pcb]
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2025-03-14 chore(main): release rp2350-decoder 0.1.0 (#27)
    * chore(main): release rp2350-decoder 0.1.0
    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
    [rp2350-decoder.kicad_pcb, rp2350-decoder.kicad_sch]
2025-03-21 fix: clean up motor CV definitions
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2025-03-23 feat: add motor control
    fix: disable directional outputs when switching direction
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2025-03-27 fix: enable motor control lockout mutex
2025-04-01 fix: use shorter cap on bottom
    [rp2350-decoder.kicad_pcb, rp2350-decoder.kicad_sch]
2025-04-01 chore(main): release rp2350-decoder 0.1.1 (#33)
    * chore(main): release rp2350-decoder 0.1.1
    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
    [rp2350-decoder.kicad_pcb, rp2350-decoder.kicad_sch]
2025-06-16 chore: add missing csv files
    [bom.csv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]
2025-06-17 fix: un-swap aux11/aux12 pins
    [e24-receiver-board.kicad_pcb, e24-receiver-board.kicad_sch]
2025-06-18 chore(main): release e24-receiver-board 0.1.2 (#38)
    * chore(main): release e24-receiver-board 0.1.2
    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
    [e24-receiver-board.kicad_pcb, e24-receiver-board.kicad_sch]
2025-06-18 fix: un-swap usb +/- and aux11/aux12 pins
    [rp2350-decoder.kicad_pcb, rp2350-decoder.kicad_sch, rp24-usb-tester.kicad_pcb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]
2025-06-18 chore: un-swap aux11/aux12 gpios
    [rp2350-decoder.kicad_pcb, rp2350-decoder.kicad_sch]
2025-06-18 chore(main): release rp24-usb-tester 0.3.2 (#40)
    * chore(main): release rp24-usb-tester 0.3.2
    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
    [rp24-usb-tester.kicad_pcb, rp24-usb-tester.kicad_sch]
2025-06-18 chore(main): release rp2350-decoder 0.1.2 (#39)
    * chore(main): release rp2350-decoder 0.1.2
    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
    [rp2350-decoder.kicad_pcb, rp2350-decoder.kicad_sch]
2025-06-21 chore: rename leds to avoid jlcpcb warnings
    [rp24-usb-tester.kicad_pcb, rp24-usb-tester.kicad_sch]
2025-06-23 fix: un-swap capacitor shutdown circuit inputs
    [pico2-test-mule.kicad_pcb, pico2-test-mule.kicad_sch, rp2350-decoder.kicad_pcb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]
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2025-06-26 fix: bump resistors to make LEDs less blinding
    [bom.csv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]
2025-06-26 chore(main): release rp24-usb-tester 0.3.3 (#43)
    * chore(main): release rp24-usb-tester 0.3.3
    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
    [rp24-usb-tester.kicad_pcb, rp24-usb-tester.kicad_sch]
2025-06-26 chore(main): release pico2-test-mule 0.2.5 (#42)
    * chore(main): release pico2-test-mule 0.2.5
    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
    [pico2-test-mule.kicad_pcb, pico2-test-mule.kicad_sch]
2025-06-26 chore(main): release rp2350-decoder 0.2.0 (#41)
    * chore(main): release rp2350-decoder 0.2.0
    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
    [rp2350-decoder.kicad_pcb, rp2350-decoder.kicad_sch]
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2025-06-26 chore(main): release pico2-test-mule 0.3.0 (#44)
    * chore(main): release pico2-test-mule 0.3.0
    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
    [pico2-test-mule.kicad_pcb, pico2-test-mule.kicad_sch]
2025-07-02 chore: switch broken video to link
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2025-07-03 chore(main): release rp2350-decoder 0.3.0 (#46)
    * chore(main): release rp2350-decoder 0.3.0
    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
    [rp2350-decoder.kicad_pcb, rp2350-decoder.kicad_sch]
2025-07-06 fix: add watchdog timer
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2025-08-02 fix: remove vdc from under connector
    Any small tweaks to the board cause rail-voltage current leakage to the connector pins
    [rp2350-decoder.kicad_pcb, rp2350-decoder.kicad_sch]
2025-08-02 chore(main): release rp2350-decoder 0.3.1 (#49)
    * chore(main): release rp2350-decoder 0.3.1
    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
    [rp2350-decoder.kicad_pcb, rp2350-decoder.kicad_sch]
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2025-09-01 fix: 5.1k resistors go to gnd
    [bom.csv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]
2025-09-01 chore: kicad drift
2025-09-01 chore(main): release rp24-usb-tester 0.3.4 (#57)
    * chore(main): release rp24-usb-tester 0.3.4
    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
    [rp24-usb-tester.kicad_pcb, rp24-usb-tester.kicad_sch]
2025-09-02 fix: switch rail ttl zeners to more common dfn1006
    [rp2350-decoder.kicad_pcb, rp2350-decoder.kicad_sch]
2025-09-02 fix: clean up silkscreen items
    [rp2350-decoder.kicad_pcb]
2025-09-02 chore(main): release rp2350-decoder 0.3.3 (#59)
    * chore(main): release rp2350-decoder 0.3.3
    * chore: update production files
    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
    [pos.csv, rp2350-decoder-CmtUser.gbr, rp2350-decoder-CuBottom.gbl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]
2026-05-25 fix(e24-receiver-board): switch to 1.0mm thick pcb
    [e24-receiver-board.kicad_pcb]
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2026-07-05 fix(motor): correct back-EMF scaling and PID configuration
    The CV53 max-EMF conversion omitted the board's 6.8k/1k sense divider
    (1/7.8), producing a PID target ~7.8x higher than the ADC can ever
    read, so the controller railed at max duty and could never regulate.
    Derive the ADC-counts-per-volt scaling (~2546 counts/V) from the
    divider resistor values as named constants.
    Normalize the PID reference and feedback to 0-1 fractions of emfMax so
    the CV-configured gains (CV52/54/55, value/10) operate in a usable
    range and the control signal is directly in duty-cycle units. Also
    pass the elapsed time to pid.Update (the integral term never
    accumulated without a sampling interval), set integral wind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
2026-07-05 feat(motor): add driver autosleep wake support for DRV8220
    H-bridge drivers with autosleep (DRV8220) fall asleep after 0.9-2.6ms
    in the coast state, which every back-EMF cutout (1-4ms) triggers, and
    then require an input held solid-high for tWAKE (65us) before
    accepting PWM again - longer than a single on-pulse at 40kHz.
    Add a DriverWakeTime setting that, when non-zero, holds the driven
    output at 100% duty (bypassing direction trim, which would otherwise
    produce a PWM waveform instead of a solid level) for that duration at
    the end of each measurement cutout before restoring normal duty. The
    blip is skipped at zero commanded duty and defaults to off for drivers
    without autosleep (MD9927/DRV8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
2026-07-05 feat(rp2350-decoder): swap motor driver to DRV8220 and add VDC bulk capacitance
    Replace the MD9927 H-bridge (12V rated VM, fed ~14V from CAP_VDC on
    15V track) with the DRV8220DRL (18V, PWM interface, autosleep-only),
    restoring supply margin for 15V operation. Firmware must set
    DriverWakeTime (~100us) for this driver's autosleep wake requirement.
    Repurpose C6 from 3.3V-rail bulk (100uF) to the CAP_VDC bus (47uF) for
    more bulk capacitance on the motor supply.
    [rp2350-decoder.kicad_pcb, rp2350-decoder.kicad_sch]
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
